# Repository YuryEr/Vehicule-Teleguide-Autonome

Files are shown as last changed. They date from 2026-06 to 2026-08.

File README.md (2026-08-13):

# Vehicule teleguide autonome (VTA)

PFE ELE795, Ecole de technologie superieure, ete 2026.  
Par : Yury Ereshchenko, Yoan Sapet, Vlad Alexandru Ilie, Ryan Leung et Serby Brian Barthelemy

Le sigle **VTA** sert partout ou la place manque : nom du point d'acces WiFi,
titre a l'ecran embarque, en-tetes des modules.

## Architecture materielle

- **Arduino UNO Q** : double processeur (Qualcomm QRB2210 MPU + STM32U585 MCU)
- **Hiwonder Tank** : chassis chenille, carte moteur I2C (0x34)
- **MPU-6050** : IMU gyroscope/accelerometre I2C (0x68)
- **Webcam USB** : detection routiere (YOLO, OpenCV). Cable modifie, alimentee
  par le convertisseur et non par le port USB-C
- **Bandeaux LED WS2812B** : 7 LEDs par bandeau : barre haute (gyrophare, feux de
  position), feux avant/arriere et clignotants de virage
- **Ecran TFT ILI9341** : 320x240, SPI materiel
- **HC-SR04** : capteur ultrason, detection de presence frontale (cone large)
- **TF-Luna** : LiDAR I2C (0x10), telemetre frontal (FOV 2 deg)
- **Servo SG90** : support orientable du LiDAR, sondage par secteurs
- **Convertisseur abaisseur (buck)** : rail 5V du montage, alimente depuis la
  batterie du chassis et non depuis l'UNO Q

## Architecture logicielle

    sketch/              MCU (STM32) : temps reel, capteurs, actionneurs
      sketch.ino           setup/loop, enregistrement des RPC Bridge
      config.h             Constantes materielles centralisees (broches, adresses, seuils)
      bus_i2c.h/cpp        Scan I2C unique au demarrage + cache de presence
      comm_bridge.h/cpp    Bridge RPC, reception des donnees de vision
      moteurs.h/cpp        Carte Hiwonder, encodeurs, I2C bas niveau
      imu.h/cpp            MPU-6050, calibration gyroscope
      deplacement.h/cpp    Machine a etats, joystick, asservissement encodeurs + gyro
      leds.h/cpp           Bandeaux WS2812B : barre, feux, clignotants
      ecran.h/cpp          Ecran ILI9341 : codes QR de connexion, infos reseau
      ultrason.h/cpp       HC-SR04, mesure d'echo bornee sur micros()
      lidar.h/cpp          TF-Luna, distance par I2C
      servo_lidar.h/cpp    SG90, PWM logiciel (support du LiDAR)
      obstacle.h/cpp       Fusion ultrason + LiDAR, sondage par secteurs
      securite.h/cpp       Veto sur les commandes moteur (mode autonome)
      evitement.h/cpp      Contournement lateral : sondage, rotation, longement
      test_capteurs.h/cpp  Releve serie periodique (bascule TEST_CAPTEURS_ACTIF)
      sketch.yaml          Profil de compilation, versions de librairies imposees

    python/              MPU (Qualcomm Linux) : serveur web, vision, Bridge
      main.py              Point d'entree, installation pip puis demarrage
      serveur_web.py       Flask + SocketIO, flux video, sequenceur de blocs
      comm_bridge.py       Communication Bridge RPC (MPU <-> MCU)
      vision.py            Feux (YOLO sur deux fenetres) et lignes
                           (seuillage adaptatif + centroide)
      boucle_vision.py     Anti-rebond des feux, cadences des deux boucles
      navigation.py        Suivi de ligne, correcteur proportionnel-derive
      requirements.txt     Dependances Python
      yolov8n.onnx         Modele de detection, entree figee a 256x256

    assets/              Interface web
      index.html           Page principale
      style.css            Styles
      app.js               Logique JS (joystick, Blockly, SocketIO)
      libs/blockly/        Editeur de blocs, embarque (pas de CDN)
      libs/socket.io.min.js  Client temps reel, embarque

Les deux librairies de `libs/` sont **embarquees volontairement** : en mode point
d'acces la carte n'a pas d'acces Internet, et un chargement par CDN laisserait
l'interface vide.

## Brochage

Toutes les broches numeriques sont declarees dans `sketch/config.h` : c'est la
seule source de verite du code. Les tableaux ci-dessous doivent lui correspondre.

### Alimentation

Le montage compte **trois sources distinctes**, et aucune ne provient du rail 5V
de l'UNO Q.

    Batterie du chassis
      |
      +---> Carte moteur Hiwonder (alimentation directe)
      |
      +---> Convertisseur abaisseur (buck) ---> Rail 5V du montage
      |                                           |
      |                                           +--> LiDAR TF-Luna
      |                                           +--> Ultrason HC-SR04
      |                                           +--> Servo SG90
      |                                           +--> Bandeaux LED WS2812B
      |                                           +--> Ecran ILI9341 (VCC et LED)
      |                                           +--> Webcam USB (VBUS seul)
      |
      +---> Masse commune <---------------------> GND de l'UNO Q

    L'UNO Q ne fournit que le 3.3V du connecteur Qwiic (IMU MPU-6050).
    Le port USB-C ne porte que les donnees de la camera, pas son alimentation.

| Composant | Tension | Source | Remarque |
|---|---|---|---|
| Carte moteur Hiwonder | Batterie | Batterie du chassis, directement | Jamais depuis l'UNO Q |
| IMU MPU-6050 | 3.3V | Connecteur Qwiic de l'UNO Q | Seul peripherique alimente par la carte |
| LiDAR TF-Luna | **5V** | Convertisseur abaisseur | **Pas** le 3.3V du Qwiic, voir plus bas |
| Ultrason HC-SR04 | 5V | Convertisseur abaisseur | Logique TRIG pilotee en 3.3V par l'UNO Q |
| Servo SG90 | 5V | Convertisseur abaisseur | Appels de courant au demarrage du mouvement |
| Bandeaux LED WS2812B | 5V | Convertisseur abaisseur | Voir le bilan de courant ci-dessous |
| Ecran ILI9341, `VCC` | **5V** | Convertisseur abaisseur | Le regulateur du module descend en 3.3V |
| Ecran ILI9341, `LED` | **5V** | Convertisseur abaisseur | Retroeclairage. Sous 3.3V l'ecran reste noir alors que le SPI repond |
| Webcam USB | 5V | Convertisseur abaisseur | **Cable modifie**, alimentation separee des donnees, voir plus bas |

**Le 5V vient d'un convertisseur abaisseur, pas de l'UNO Q.** Un module buck
descend la tension de la batterie du chassis a 5V et alimente tous les
peripheriques de puissance. Deux raisons : le rail 5V de la carte n'a pas la
reserve de courant necessaire aux bandeaux et au servo, et faire transiter ces
appels de courant par la carte de commande y ferait chuter la tension au moment
precis ou elle pilote.

**La masse doit rester commune, sinon rien ne fonctionne.** C'est la contrepartie
obligatoire d'une alimentation separee : le GND du convertisseur, celui de la
batterie et celui de l'UNO Q doivent etre relies. Les signaux de commande sortent
de l'UNO Q et sont lus par des composants alimentes ailleurs ; sans reference de
tension partagee, un niveau haut n'a plus de sens pour eux et rien ne repond,
alors que chaque bloc pris isolement semble correctement alimente.

**L'ecran a besoin de 5V sur ses deux entrees d'alimentation.** `VCC` traverse le
regulateur du module de decouplage, et `LED` alimente le retroeclairage. Une erreur
classique consiste a n'alimenter que `VCC` : le controleur repond correctement sur
le SPI, le code s'execute sans erreur, mais la dalle reste noire faute de
retroeclairage.

**Bilan de courant des bandeaux.** Un WS2812B consomme environ 60 mA au blanc
plein (20 mA par canal). Le montage porte 14 LEDs, soit **environ 840 mA** dans le
pire cas, `LUMINOSITE_BANDEAU` etant a 255. Le cas ne se presente pas en usage
normal, les feux etant blancs ou rouges et la barre rarement toute allumee, mais
c'est ce chiffre qui dimensionne le convertisseur : il doit tenir cette pointe en
plus du servo et des deux capteurs. Si les LEDs scintillent, verifier le calibre du
convertisseur avant de soupconner le code, et au besoin baisser
`LUMINOSITE_BANDEAU`.

### Webcam USB, cable modifie

Le cable de la camera est **ouvert et rebranche sur deux sources** : les quatre
conducteurs ne vont plus tous au meme endroit.

| Conducteur | Destination | Role |
|---|---|---|
| VBUS (rouge, 5V) | Convertisseur abaisseur | Alimentation de la camera |
| D+ (vert) | Port USB-C de l'UNO Q | Donnee |
| D- (blanc) | Port USB-C de l'UNO Q | Donnee |
| GND (noir) | Masse commune | Reference, partagee avec le convertisseur et l'UNO Q |

Deux raisons imposent ce montage, constatees sur cette carte :

1. **L'UNO Q n'alimente pas la camera par son port USB-C.** Le courant disponible
   sur ce port ne suffit pas a la faire demarrer.
2. **Brancher quoi que ce soit sur l'USB-C fait perdre le 5V de la carte.** Le
   rail 5V de l'UNO Q s'effondre des qu'un peripherique occupe ce port, ce qui
   priverait au passage tout ce qui en dependrait encore.

Prendre le VBUS sur le convertisseur resout les deux d'un coup : la camera a le
courant qu'il lui faut, et le port USB-C ne sert plus qu'a transporter les
donnees. **La masse doit rester commune** entre le convertisseur et l'UNO Q, sinon
la paire differentielle D+/D- n'a plus de reference et l'hote ne voit aucun
peripherique.

C'est aussi la raison pour laquelle l'ensemble du montage est alimente par le
convertisseur : le 5V de la carte n'est pas disponible de facon fiable des que la
camera est branchee.

### Vue d'ensemble des broches occupees

| Broche UNO Q | Utilisation |
|---|---|
| Qwiic (Wire1) | Carte moteur 0x34, IMU 0x68, LiDAR 0x10 |
| D2 | Ultrason : TRIG |
| D3 | Ultrason : ECHO |
| D5 | Servo SG90 : signal |
| D6 | Bandeau LED avant : data |
| D7 | Bandeau LED arriere : data |
| D8 | Ecran : RESET |
| D9 | Ecran : DC |
| D10 | Ecran : CS |
| D11 | Ecran : MOSI (SPI materiel) |
| D12 | Ecran : MISO (SPI materiel, non utilise en ecriture) |
| D13 | Ecran : SCK (SPI materiel) |

### Peripheriques I2C sur le bus Qwiic (`Wire1`)

Les trois peripheriques partagent le meme bus. Aucune adresse n'entre en conflit.

| Peripherique | Adresse | Alimentation | Particularite |
|---|---|---|---|
| Carte moteur Hiwonder | 0x34 | Alimentation propre du chassis | Aucune |
| IMU MPU-6050 | 0x68 | 3.3V du Qwiic | Aucune |
| LiDAR TF-Luna | 0x10 | **5V** du convertisseur | Broche **CFG a la masse** + power cycle |

**TF-Luna, alimenter en 5V.** Le capteur demande 3.7-5.2V ; le 3.3V du Qwiic est
sous son minimum. On utilise le Qwiic pour SDA/SCL/GND, mais VCC vient du rail
5V du convertisseur abaisseur.

**TF-Luna, CFG a la masse, puis power cycle.** CFG (broche 5) reliee a GND
selectionne le mode I2C. Le mode est **lu au demarrage du capteur** : apres avoir
branche CFG, il faut **couper et remettre l'alimentation**, sinon le capteur reste
en UART et n'apparait jamais sur le bus.

**Sans aucun peripherique sur le Qwiic**, les lignes flottent faute de resistances
de tirage et toutes les transactions I2C partent en timeout.

### Ultrason HC-SR04

| Broche du capteur | Broche UNO Q | Role |
|---|---|---|
| VCC | 5V du convertisseur | Alimentation |
| TRIG | D2 | Declenchement de la salve (impulsion 10 us) |
| ECHO | D3 | Duree de l'echo, en direct (sans pont diviseur) |
| GND | GND | Masse |

**ECHO se branche en direct.** Le montage a d'abord utilise un pont diviseur
22k/47k pour ramener la sortie 5V du capteur a ~3.4V. Il s'est avere inutile : la
liaison directe fonctionne correctement sur notre carte. A noter pour la
reproductibilite : la tolerance 5V des broches D de l'UNO Q n'est **pas garantie**
par Arduino (seuls certains pads STM32U585 sont 5V-tolerants, et jamais en mode
analogique). Le montage fonctionne, mais il sort de la plage documentee.

**TRIG est pilote en 3.3V** alors que le seuil du HC-SR04 se situe vers 3.5V.
Cela fonctionne sur nos exemplaires ; un capteur qui ne declencherait jamais est
la premiere piste a examiner.

### Servo de balayage SG90

| Fil du servo | Broche UNO Q | Role |
|---|---|---|
| Orange / jaune | D5 | Signal PWM (genere en logiciel) |
| Rouge | 5V du convertisseur | Alimentation |
| Brun / noir | GND | Masse, commune avec la carte et le convertisseur |

La librairie `Servo` est inutilisable sur ce core (voir plus bas) : l'impulsion est
generee par `servo_lidar.cpp`.

### Bandeaux LED WS2812B

| Broche du bandeau | Broche UNO Q | Role |
|---|---|---|
| DI (bandeau avant) | D6 | Donnees. Sur WS2813, relier BI a la meme broche |
| DI (bandeau arriere) | D7 | Donnees |
| VCC | 5V du convertisseur | Alimentation, voir le bilan de courant |
| GND | GND | Masse, commune avec la carte |

Chaque bandeau porte **7 LEDs en serie sur une seule ligne de donnees**, decoupees
en deux zones par le logiciel :

| Pixels | Zone | Role |
|---|---|---|
| 0 a 4 | Barre haute | Feux de position ou gyrophare |
| 5 | Feu droit | Blanc a l'avant, rouge a l'arriere, orange en clignotant |
| 6 | Feu gauche | Idem |

La logique de l'UNO Q est en 3.3V : le seuil des WS2812B est limite mais fonctionne
en pratique, aucun level-shifter n'a ete necessaire.

### Ecran TFT ILI9341 sur SPI materiel

| Broche de l'ecran | Broche UNO Q | Role |
|---|---|---|
| CS | D10 | Selection du peripherique |
| RESET | D8 | Reinitialisation |
| DC (ou RS) | D9 | Choix donnee / commande |
| SDI (MOSI) | D11 | Donnees vers l'ecran |
| SCK | D13 | Horloge SPI |
| SDO (MISO) | D12 | Donnees depuis l'ecran, non utilise en ecriture |
| VCC | **5V** du convertisseur | Alimentation du module |
| LED | **5V** du convertisseur | Retroeclairage, indispensable pour voir quoi que ce soit |
| GND | GND | Masse |

Les six lignes de signal sont celles declarees dans `config.h` et le materiel SPI de
la carte. Aucun level-shifter n'est necessaire : l'ILI9341 accepte la logique 3.3V
de l'UNO Q sur ses entrees de signal, mais son alimentation et son retroeclairage
demandent tous deux **5V**. Un ecran noir avec un SPI qui repond signale presque
toujours un `LED` non alimente.

## Librairies Arduino : versions critiques

Le core Zephyr de l'UNO Q ne supporte pas les librairies qui accedent directement
aux registres (style AVR). **Les versions ci-dessous sont obligatoires** : des versions
plus anciennes compilent parfois sans erreur mais ne fonctionnent pas au runtime.

```yaml
# sketch/sketch.yaml
profiles:
  default:
    fqbn: arduino:zephyr:unoq
    platforms:
      - platform: arduino:zephyr
    libraries:
      - Adafruit NeoPixel (1.15.5)
      - Adafruit GFX Library (1.12.6)
      - Adafruit ILI9341 (1.6.3)
      - Adafruit BusIO (1.17.4)
      - QRCode (0.0.1)
default_profile: default
```

| Librairie | Version | Pourquoi cette version |
|---|---|---|
| Adafruit NeoPixel | **1.15.5** | Les versions anterieures (ex. 1.12.0) **compilent** mais leur timing bit-bang 800 kHz ne produit **aucun signal** sur STM32U585/Zephyr. Symptome : LEDs completement eteintes. |
| Adafruit BusIO | **1.17.4** | Contient le guard `#elif defined(__MBED__) \|\| defined(__ZEPHYR__)` qui desactive `BUSIO_USE_FAST_PINIO`. Les versions < 1.15 **ne compilent pas** (erreur `portOutputRegister` / `digitalPinToPort`). |
| Adafruit GFX / ILI9341 | 1.12.6 / 1.6.3 | Dependances de l'ecran, dernieres versions stables. |
| QRCode | 0.0.1 | Generation des codes QR de connexion. C pur, sans acces registre ni allocation dynamique, le tampon est fourni par l'appelant, ce qui la rend compatible avec le core Zephyr. |

Les autres librairies visibles a la compilation (`Arduino_RouterBridge`, `Arduino_RPClite`,
`MsgPack`, `DebugLog`, `ArxTypeTraits`, `ArxContainer`, `Wire`) sont des dependances
**automatiques** du systeme Bridge et du core. Ne pas les epingler dans `sketch.yaml` :
elles forment un ensemble coherent livre avec le Bridge.

### Librairie a ne pas utiliser

**`Servo` est inutilisable sur ce core.** Des qu'elle coexiste avec NeoPixel, l'edition
de liens echoue sur `undefined reference to noInterrupts()/interrupts()`. Le servo de
balayage est donc pilote par un PWM logiciel dans `sketch/servo_lidar.cpp` : l'impulsion
est mesuree par attente active sur `micros()`, `delayMicroseconds()` etant imprecis sous
le scheduler Zephyr.

## Guide de deploiement sur Arduino UNO Q

### Prerequis

- Arduino App Lab installe (v0.8+)
- Arduino UNO Q connecte par USB au PC
- Webcam USB branchee

### Etape 1 : Configuration de l'Arduino UNO Q en mode point d'acces

Creer un point d'acces (AP), remplacer le SSID et le mot de passe :

```bash
nmcli device wifi hotspot ssid VTA password admin123 ifname wlan0
```

Appliquer automatiquement a chaque demarrage :

```bash
nmcli connection modify Hotspot connection.autoconnect yes
```

En mode point d'acces la carte n'a **pas d'acces Internet** : `main.py` ignore alors
l'installation pip (enveloppee dans un `try/except`) et demarre le serveur avec les
dependances deja presentes. Faire au moins un premier demarrage **connecte a Internet**
pour que les dependances Python s'installent.

### Etape 2 : Configuration des ports

Dans `app.yaml` a la racine du projet, s'assurer que le port du serveur web est expose :

```yaml
ports: [7000]
```

Sans cette ligne, le conteneur Docker tourne mais le port n'est pas accessible de l'exterieur.

### Etape 3 : Deployer le code

1. Ouvrir le projet dans Arduino App Lab
2. Cliquer **Run** (bouton vert)
3. App Lab va :
   - Compiler et flasher le sketch sur le MCU (STM32)
   - Creer un conteneur Docker sur le MPU (Qualcomm)
   - Installer automatiquement les dependances Python (premiere fois ~30s)
   - Demarrer le serveur web

### Etape 4 : Acceder a l'interface

1. Trouver l'IP de la carte (affichee en bas d'App Lab, ex: `192.168.137.52`)
2. Ouvrir dans un navigateur : `http://<IP>:7000`

### Depannage

| Probleme | Solution |
|---|---|
| Page web ne charge pas | Verifier `ports: [7000]` dans `app.yaml` |
| Camera non disponible | La camera USB n'est pas sur l'index attendu, le code scanne automatiquement `/dev/video0` a `/dev/video9`. Si aucun index ne repond, verifier le cable modifie : VBUS sur le convertisseur, D+ et D- sur l'USB-C, **masse commune**. Sans masse partagee la paire differentielle n'a pas de reference et l'hote ne detecte aucun peripherique |
| Terminal Python vide | Les dependances pip s'installent au premier demarrage, patienter ~30s |
| Erreur `ModuleNotFoundError` | Verifier que `requirements.txt` est a jour et relancer Run |
| Le serveur ne demarre pas hors ligne | `main.py` enveloppe l'install pip dans un `try/except` : en mode point d'acces (sans Internet) l'install est ignoree et le serveur demarre quand meme |
| `Error: verify failed in bank at 0x08000000` | Le flash a echoue : le MCU tourne **l'ancien code**. Relancer Run (parfois 2-3 fois) jusqu'a un flash propre. Si une modification semble sans effet, c'est souvent ca. |
| `ld: file truncated` / `invalid string offset` / segfault du linker | Cache de compilation corrompu. Supprimer `.cache/sketch` sur la carte (garder `.cache/.venv` qui contient l'environnement Python) : `rm -rf ~/ArduinoApps/tankets_ele795/.cache/sketch` |
| LEDs completement eteintes | Verifier `Adafruit NeoPixel (1.15.5)` dans `sketch.yaml`, les versions anterieures compilent mais ne pilotent rien |
| Ecran : erreur `portOutputRegister` a la compilation | Verifier `Adafruit BusIO (1.17.4)`, les versions < 1.15 ne compilent pas sur Zephyr |
| Ecran noir alors que le code s'execute | La broche `LED` du module n'est pas alimentee. Le controleur repond sur le SPI et le programme se deroule normalement, mais sans retroeclairage la dalle reste noire. `VCC` **et** `LED` demandent 5V |
| LEDs qui scintillent | Calibre du convertisseur abaisseur. 14 WS2812B au blanc plein demandent environ 840 mA, en plus du servo et des capteurs. Verifier le convertisseur avant le code, au besoin baisser `LUMINOSITE_BANDEAU` |
| Un peripherique alimente ne repond a rien | Masse commune. Le convertisseur, la batterie et l'UNO Q doivent partager leur GND, sans quoi les signaux de commande n'ont plus de reference et chaque bloc semble pourtant correctement alimente |
| Servo qui tremble sur place sans se deplacer | Comportement attendu si `SERVO_MAINTIEN_MS` est augmente : chaque impulsion regeneree porte le jitter de l'attente active. Le train d'impulsions doit s'arreter une fois la cible atteinte |
| LiDAR `capteur present : NON` | CFG (broche 5) a la masse ? Alimentation >= 3.7V ? **Power cycle apres avoir branche CFG** ? SDA/SCL non inverses ? |
| Un capteur absent rend la carte muette | Le Bridge est enregistre **avant** les inits materielles dans `setup()`, donc le controle survit a un capteur defaillant. Si le probleme persiste, verifier qu'aucune init bloquante n'a ete deplacee avant les `provide_safe`. |
| `[Bridge.read_loop] 'utf-8' codec can't decode byte ...` puis tous les RPC qui expirent apres 10 s | La sortie serie du MCU partage son lien avec les RPC du Bridge. Sous une ecriture serie soutenue, le multiplexage perd une frontiere de trame et la boucle de lecture du Bridge meurt : plus aucun appel n'aboutit jusqu'au redemarrage. **Commenter `TEST_CAPTEURS_ACTIF` dans `test_capteurs.h`**, et n'ecrire sur le port serie que ponctuellement. Symptome typique : une sequence de blocs qui casse apres une dizaine de commandes. |

### Diagnostic I2C

Pour verifier ce qui repond sur le bus Qwiic, ajouter temporairement dans `setup()`
apres `Wire1.begin()` :

```cpp
for (uint8_t addr = 1; addr < 127; addr++) {
    Wire1.beginTransmission(addr);
    if (Wire1.endTransmission() == 0) {
        Serial.print("[i2c] Trouve a 0x");
        Serial.println(addr, HEX);
    }
}
```

Attendu : `0x34` (moteurs), `0x68` (IMU), `0x10` (LiDAR).

## Conventions de code

- **Python** : snake_case (fonctions, variables, fichiers)
- **JavaScript** : camelCase (fonctions, variables), UPPER_CASE (constantes)
- **HTML** : kebab-case (IDs, classes)
- **C/Arduino** : PascalCase + prefixe module (ex: `CommBridge_Initialiser`)
- **Fichiers .h** : documentation en francais, format bloc majuscule
- **Constantes materielles** : centralisees dans `sketch/config.h`, jamais dans les modules
- **Modules capteurs** : pattern `X_Initialiser()` / `X_MettreAJour()` / `X_Valeur()`,
  avec mise en cache non bloquante rafraichie dans `loop()`

## Modes de conduite

Le MCU connait deux regimes, fixes par la RPC `definir_mode`. L'interface web
ajoute un troisieme usage, le mode blocs, qui n'est pas un mode du MCU mais une
sequence de commandes envoyees depuis le MPU.

| Mode | Veto de securite | Origine des commandes |
|---|---|---|
| Manuel | Aucun | Joystick de l'interface web |
| Autonome | Actif | Suivi de ligne calcule sur le MPU |
| Blocs | Aucun | Sequenceur de `serveur_web.py`, un bloc a la fois |

**Le veto ne s'applique qu'en mode autonome.** En manuel le pilote voit le
vehicule et garde le controle complet, y compris pour l'approcher volontairement
d'un obstacle. Le laisser actif rendrait le pilotage incomprehensible, la carte
refusant des commandes sans que rien ne l'explique a l'ecran.

Le veto ne bloque que les **avances**, c'est-a-dire les commandes ou les deux
chenilles poussent vers l'avant. Les rotations et la marche arriere restent
autorisees : ce sont precisement les manoeuvres qui degagent le vehicule.

Deux causes distinctes le declenchent, et elles n'ont pas la meme suite :

| Cause | Consequence |
|---|---|
| Obstacle sous `OBSTACLE_SEUIL_CM` | Arret, puis lancement du contournement |
| Feu rouge ou jaune detecte | Arret seul, reprise des que le feu passe au vert |

Le jaune est traite comme le rouge : devant un feu sur le point de changer,
s'arreter est le comportement attendu. Une detection de feu expire au bout de
`FEU_AGE_MAX_MS`, faute de quoi une perte de la liaison de vision immobiliserait
le vehicule indefiniment.

## Detection d'obstacles et contournement

### Fusion des deux capteurs

La distance frontale retenue est la **plus petite des mesures valides** entre
l'ultrason et le LiDAR. Les deux capteurs ne mesurent pas la meme chose et c'est
la raison de les garder tous les deux :

| Capteur | Champ | Role |
|---|---|---|
| HC-SR04 | Cone large | Presence d'un obstacle quelque part devant |
| TF-Luna | 2 degres | Telemetre precis, mais aveugle a ce qui n'est pas dans l'axe |

Un LiDAR seul manque un obstacle decale de quelques degres ; un ultrason seul
donne une distance grossiere. Chaque mesure est ramenee au pare-choc avant par
`ULTRASON_RECUL_CM` et `LIDAR_RECUL_CM`, sans quoi la fusion comparerait deux
distances prises depuis deux origines differentes.

### Machine a etats du contournement

Le servo n'existe que pour le sondage : il n'y a pas de balayage permanent, le
champ du LiDAR etant trop etroit pour cartographier quoi que ce soit en un temps
raisonnable.

Le trajet forme un **trapeze** : une diagonale qui ecarte le vehicule de la
ligne, un segment parallele qui depasse l'obstacle, puis une diagonale de retour
vers la ligne.

                       EVITEMENT_LONGEMENT_M
                      +---------------+           segment parallele a la ligne
                     /                 \      angles 1 et 2 : ANGLE_DEG
        ____________/    [obstacle]     \___  angle 3 : ANGLE_RETOUR_DEG
             ligne suivie

    REPOS
      | obstacle detecte en mode autonome
      v
    PAUSE --> SONDAGE             trois secteurs, +/- OBSTACLE_ECART_SONDAGE_DEG
      |                           retient le cote le plus degage
      v
    PAUSE --> ROTATION_ALLER      pivote de EVITEMENT_ANGLE_DEG vers ce cote
      |
      v
    PAUSE --> AVANCE_DIAGONALE    avance de EVITEMENT_DISTANCE_M
      |
      v
    PAUSE --> ROTATION_PARALLELE  rend l'angle d'ecartement, cap parallele
      |                           a la ligne
      v
    PAUSE --> AVANCE_PARALLELE    avance de EVITEMENT_LONGEMENT_M
      |
      v
    PAUSE --> ROTATION_RETOUR     EVITEMENT_ANGLE_RETOUR_DEG vers la ligne
      |
      v
    REPOS                         le suivi de ligne reprend la main

**Chaque etape est precedee d'une immobilisation de `EVITEMENT_PAUSE_MS`.** La
carte moteur maintient sa derniere consigne tant qu'on ne lui en donne pas
d'autre : sans arret explicite, les etapes s'enchainent en roulant et se
superposent.

**Les trois rotations ne sont pas dans le meme sens.** La premiere ecarte de la
ligne, du cote retenu par le sondage. Les deux suivantes vont a l'oppose : la
deuxieme rend exactement l'angle d'ecartement et remet le cap d'origine, la
troisieme dirige le vehicule vers la ligne, qu'il recroise. Sans cette troisieme
rotation, il roulerait parallelement a la ligne sans jamais la revoir et le
suivi s'arreterait apres `MISS_MAX` cycles.

**La rotation de retour est plus faible que celle d'ecartement**, et pour une
raison qui n'a rien de geometrique : a 45 degres la ligne sort du champ de la
camera avant d'etre recroisee, et le suivi s'arrete sans jamais la retrouver.
A 20 degres elle reste en vue, au prix d'une approche plus longue.

| Angle de retour | Distance parcourue avant de recroiser la ligne |
|---|---|
| 45 degres | 45 cm, mais ligne hors du champ |
| 30 degres | 64 cm |
| **20 degres** | **93 cm, valeur retenue** |
| 15 degres | 123 cm |

**La deuxieme rotation rend l'angle cumule, pas une valeur fixe.** Si la voie
reste bloquee apres la premiere rotation, un cran supplementaire est ajoute,
jusqu'a `EVITEMENT_ESSAIS_MAX` fois. La remise parallele doit alors annuler le
total, sans quoi le segment cense etre parallele partirait de travers.

**Dimensionnement.** L'ecart lateral obtenu vaut `EVITEMENT_DISTANCE_M` multiplie
par le sinus de l'angle d'ecartement, soit 32 cm pour 45 cm a 45 degres. Noter
que la constante decrit la distance **parcourue** sur la diagonale, pas l'ecart
obtenu. Il doit depasser le
demi-encombrement de l'obstacle, sans quoi le segment parallele le percute. Le
segment parallele doit lui-meme depasser la profondeur de l'obstacle avant que le
vehicule ne se reoriente vers la ligne.

## Ecran de connexion

L'ecran affiche une page unique portant **deux codes QR cote a cote**, de facon
qu'un visiteur puisse rejoindre le vehicule sans que personne ne lui dicte un mot
de passe.

| Code QR | Contenu | Effet au scan |
|---|---|---|
| Gauche | `WIFI:T:WPA;S:<ssid>;P:<mdp>;;` | Propose de rejoindre le point d'acces |
| Droite | `http://<ip>:7000` | Ouvre l'interface dans le navigateur |

Le format d'adhesion WiFi `WIFI:` est un schema de fait defini par le projet
ZXing, reconnu nativement par iOS 11 et par Android 10 et versions ulterieures.

| Constante | Valeur | Role |
|---|---|---|
| `QR_VERSION` | 3 | 29x29 modules, 53 octets en correction basse |
| `QR_TAILLE_MODULE` | 4 | Cote d'un module, en pixels |
| `QR_ZONE_SILENCE` | 4 | Marge blanche en modules, exigee par la norme |

La zone de silence n'est pas decorative : sans elle, un lecteur ne delimite pas
le symbole et le scan echoue sur la plupart des telephones.

### Origine des trois informations

Les trois valeurs sont des constantes de `sketch/config.h`, et **doivent
correspondre a la commande `nmcli` du guide de deploiement** :

| Constante | Valeur | Origine |
|---|---|---|
| `RESEAU_SSID` | `VTA` | Choisi dans la commande `nmcli` |
| `RESEAU_MOT_DE_PASSE` | `admin123` | Idem |
| `RESEAU_IP` | `10.42.0.1` | Consequence de la commande, voir ci-dessous |

L'adresse n'est pas arbitraire : en mode partage, NetworkManager attribue
**10.42.0.1** a l'interface et distribue le reste du sous-reseau 10.42.0.0/24
aux clients. Creer le point d'acces fixe donc l'adresse au meme titre que le
SSID, et rien n'a besoin de la decouvrir a l'execution.

**Cela ne tient que si la carte cree son reseau.** Si elle en rejoint un, son
adresse vient d'un DHCP : il faut alors la relever avec `ip addr show wlan0` et
la reporter dans `config.h`. C'est la contrepartie assumee de la simplicite,
acceptable parce que le mode point d'acces est celui du deploiement.

## Signalisation lumineuse

Chaque bandeau porte 7 LEDs sur une seule ligne de donnees, decoupees en deux
zones par le logiciel. Les deux zones partagent la meme luminosite materielle :
le contraste entre la barre et les feux se fait par les valeurs RVB.

| Zone | Pixels | Comportement |
|---|---|---|
| Barre haute | 0 a 4 | Eteinte, feux de position, ou gyrophare (`PERIODE_GYROPHARE_MS`) |
| Feux | 5 et 6 | Blancs a l'avant, rouges a l'arriere |
| Clignotants | 5 ou 6 | Orange sur le cote du virage (`PERIODE_CLIGNOTANT_MS`) |

Le cote de chaque pixel est fixe par `PIXEL_COTE_DROIT` et `PIXEL_COTE_GAUCHE` :
les bandeaux avant et arriere se faisant face, l'ordre physique des pixels
s'inverse de l'un a l'autre.

## Contrat RPC Bridge (Python vers MCU)

| Fonction | Parametres | Description |
|---|---|---|
| `joy_x`, `joy_y` | float | Pilotage manuel joystick |
| `roues` | int, int (0-100, positifs) | Vitesse par cote, suivi de ligne |
| `avancer_metres` | float (positif) | Deplacement avant asservi |
| `reculer_metres` | float (positif) | Deplacement arriere asservi |
| `tourner_gauche_deg` | float (positif) | Rotation gauche asservie |
| `tourner_droite_deg` | float (positif) | Rotation droite asservie |
| `arreter_mouvement` | aucun | Arret d'urgence |
| `mouvement_actif` | aucun, retourne int (0/1) | Polling fin de mouvement |
| `definir_mode` | int | 0=manuel (aucun veto), 1=autonome (veto sur obstacle) |
| `veto_actif` | aucun, retourne int (0/1) | Le MCU refuse-t-il d'avancer ? |
| `cause_arret` | aucun, retourne int | 0=voie libre, 1=obstacle, 2=feu rouge ou jaune |
| `mode_bandeaux` | int | Barre haute : 0=eteint, 1=position, 2=gyrophare |
| `mode_phares` | int (0/1) | Feux : blanc a l'avant, rouge a l'arriere |
| `lire_ultrason_cm` | aucun, retourne int | Distance frontale HC-SR04 (cm), plafond `ULTRASON_DISTANCE_MAX` = voie degagee |
| `lire_lidar_cm` | aucun, retourne int | Distance frontale TF-Luna (cm), -1 si invalide |
| `servo_angle` | int (0-180) | Oriente le servo de balayage, 90 = droit devant |
| `obstacle_frontal_cm` | aucun, retourne int | Distance fusionnee ultrason + LiDAR (cm) |
| `obstacle_detecte` | aucun, retourne int (0/1) | Obstacle sous `OBSTACLE_SEUIL_CM` |
| `lancer_sondage` | aucun | Sonde les trois secteurs (~1 s, vehicule a l'arret) |
| `cote_degage` | aucun, retourne int | 0 = sondage en cours, 1 = gauche, 2 = droite |

RPC dans l'autre sens (MCU recoit du MPU) : `on_feu(bool, int, int)`. L'ecart de
ligne n'est pas transmis au MCU : le suivi de ligne est calcule sur le MPU, qui
n'envoie que la consigne de vitesse par `roues`.

**Note** : le Bridge ne transmet pas correctement les nombres negatifs. Toujours envoyer
des valeurs positives, le sens est gere par des fonctions dediees cote MCU (c'est
pourquoi `roues` prend deux vitesses positives plutot qu'un differentiel signe).

## Detection des feux de signalisation

L'entree du modele YOLOv8n exporte en ONNX est **figee a 256 pixels de cote**.
Redimensionner l'image entiere pour l'y faire tenir divise la largeur apparente
des objets par plus de deux : un feu de 6 cm vu a 1 m passe d'environ 33 pixels
a 13, en dessous de ce que le modele detecte de facon fiable. C'est pourquoi le
feu n'etait vu qu'au dernier moment.

Le modele recoit donc des **fenetres prelevees a la resolution native** plutot
que l'image comprimee. Deux fenetres, aux bords gauche et droit : le feu borde
la chaussee et n'apparait jamais au centre du champ.

    Image capturee par la webcam : 640 x 360

    x=0          x=256   x=384        x=640
    +--------------+-------+--------------+   y=0
    |##############|       |##############|
    |## FENETRE  ##| bande |## FENETRE  ##|
    |##  GAUCHE  ##|  non  |##  DROITE  ##|
    |##256 x 256 ##|analyse|##256 x 256 ##|
    |##############| 128px |##############|
    |XXXXXXXXXXXXXX|=======|XXXXXXXXXXXXXX|   y=216
    +--------------+=======+--------------+   y=256
    |=====================================|
    |== ROI SUIVI DE LIGNE : 640 x 144 ===|
    +-------------------------------------+   y=360

    ###  fenetres soumises au modele, prelevees a la resolution native
    ===  region du seuillage adaptatif et du centroide de la ligne
    XXX  recouvrement des deux traitements, 40 pixels de haut

Les deux traitements lisent la meme image mais ne s'ignorent pas
geometriquement : les fenetres descendent jusqu'a `y = 256` et le ROI de ligne
commence a `y = 216`, soit 40 pixels communs. Sans consequence, les deux chaines
etant independantes, mais a savoir avant de deplacer l'une ou l'autre.

Une bande centrale de 128 pixels de large n'est jamais soumise au modele. C'est
sans consequence pour un feu de bord de voie, mais un feu place au centre du
champ ne serait pas detecte.

Le feu conserve ainsi sa taille reelle, ce qui **double environ la portee de
detection** sans avoir a reexporter le modele.

Les deux fenetres impliquent **deux inferences par cycle**. Si la charge du MPU
devient genante, augmenter `PERIODE_INFERENCE` dans `boucle_vision.py` : un feu
est immobile, sa detection ne demande pas une cadence elevee.

La couleur du feu n'est pas donnee par le modele, qui ne connait que la classe
`traffic light` de COCO. Elle est determinee ensuite, par comptage de pixels dans
trois plages HSV appliquees a la boite detectee. Le rouge occupe **deux** plages,
la teinte passant par zero en HSV.

Les constantes de reglage sont regroupees plus bas, dans **Constantes de reglage
du MPU**.

## Suivi de ligne autonome

Le module `python/navigation.py` implemente un correcteur **proportionnel-derive** :
la vision fournit l'ecart lateral (pixels) entre le centre de la ligne et le centre
de l'image, et on ralentit la roue du cote vers lequel tourner. Les deux roues avancent
toujours (valeurs positives, contrainte du Bridge).

Le terme derive est indispensable : la vision tourne a 10 Hz et le Bridge ajoute sa
latence. Avec un correcteur purement proportionnel, la correction arrive alors que
l'ecart a deja change de signe : le vehicule oscille d'un bord a l'autre et finit par
perdre la ligne.

| Constante | Valeur | Role |
|---|---|---|
| `VITESSE_BASE` | 15 | Vitesse des deux roues en ligne droite (0-100) |
| `KP_LATERAL` | 0.015 | Gain proportionnel : pixels d'ecart vers unites de vitesse |
| `KD_LATERAL` | 0.035 | Gain derive : s'oppose aux variations de l'ecart, amortit le depassement |
| `ZONE_MORTE_PX` | 35 | Ecart en deca duquel la ligne est jugee centree |
| `CORRECTION_MAX` | 8 | Correction maximale, garde les deux roues en avant |
| `SENS` | -1 | Oriente la correction. **-1** est la valeur validee sur le montage actuel, a reprendre si la camera est reorientee |
| `MISS_MAX` | 8 | Cycles sans ligne avant l'arret |

### Procedure de reglage

Un seul parametre a la fois, dans cet ordre, sinon il est impossible de savoir
lequel agit.

1. **`KD_LATERAL = 0`**, puis diviser `KP_LATERAL` par deux jusqu'a disparition de
   l'oscillation. Le vehicule sera mou en virage : c'est attendu. Noter la valeur.
2. **Remonter `KD_LATERAL`** par paliers jusqu'a retrouver du mordant en virage sans
   redepasser. Trop haut, il rend le vehicule nerveux sur le bruit du centroide.
3. **`ZONE_MORTE_PX`** : augmenter jusqu'a ce que le vehicule cesse de fretiller en
   ligne droite. Trop haute, il louvoie lentement autour de la ligne.
4. **`VITESSE_BASE`** en dernier. Toute augmentation de vitesse deteriore un reglage
   trouve plus lentement, et impose de reprendre a l'etape 1.

`KP_LATERAL` et `KD_LATERAL` dependent de la **resolution de la camera**, l'ecart etant
exprime en pixels bruts. Un changement de resolution invalide tout le reglage.

## Constantes de reglage du MCU

Toutes dans `sketch/config.h`. Les valeurs indiquees sont celles du montage
actuel ; celles marquees d'une etoile ont ete relevees par la mesure, les autres
sont des valeurs d'origine ou reprises d'une documentation.

### Calibration mecanique

| Constante | Valeur | Role |
|---|---|---|
| `DIAMETRE_ROUE_MM` | 65.0 | Diametre du barbotin |
| `RATIO_REDUCTEUR` | 50.0 | **Jamais mesure**, voir l'avertissement ci-dessous |
| `IMPULSIONS_PAR_TOUR` | 44.0 | Impulsions par tour d'aimant du JGB37-520 |
| `SENSIBILITE_GYRO` | 131.0 | LSB par deg/s a pleine echelle +/-250 |

`DIAMETRE_ROUE_MM` et `RATIO_REDUCTEUR` n'interviennent que par leur **produit**
dans `Moteurs_PulsesEnMetres`, et le glissement de la chenille s'y cache : ce sont
des constantes ajustees par la mesure, pas des grandeurs relevables sur une fiche
produit. Le fabricant annonce 90 pour le JGB37-520, valeur qui donne le double de
la distance reelle sur ce chassis. Reglage : commander 2 m, mesurer, puis
`RATIO_nouveau = RATIO_actuel * (commandee / mesuree)`.

### Deplacements asservis

| Constante | Valeur | Role |
|---|---|---|
| `VITESSE_DEPLACEMENT` | 12 | Translation, en impulsions par 10 ms |
| `VITESSE_ROTATION` | 11 | Rotation, volontairement lente pour la reproductibilite |
| `ROT_MARGE_ARRET_DEG` | 10.0 * | Compensation de l'inertie de fin de rotation |
| `ROT_MARGE_LENTE_DEG` | 20.0 | Debut de l'approche lente, a garder au-dessus de la marge d'arret |
| `AVANCE_TRIM_NUM` / `_DEN` | 5 / 16 * | Compensation de derive, fraction d'unite de consigne |
| `REEMISSION_MOTEUR_MS` | 100 | Repetition de la consigne pendant un mouvement asservi |
| `TIMEOUT_AVANCE_MS` | 12000 | Abandon d'une avance qui n'aboutit pas |
| `TIMEOUT_ROTATION_MS` | 8000 | Abandon d'une rotation qui n'aboutit pas |

En boucle fermee, l'unite de vitesse est le **nombre d'impulsions par 10 ms** et
la plage utile va jusqu'a environ 50 selon la charge et la tension.

Toute modification de `VITESSE_ROTATION` impose de reprendre les deux marges :
commander 90 puis 180 degres et mesurer. Un ecart **constant** designe l'inertie,
donc `ROT_MARGE_ARRET_DEG` ; un ecart **proportionnel** designe `SENSIBILITE_GYRO`.

Le trim de derive est regle **pour 1 m**. Sur 2 m le vehicule decrit une legere
courbe en S : un transitoire de demarrage s'ajoute a la derive etablie, et une
constante ne peut annuler leur somme qu'a une seule distance.

### Pilotage manuel

| Constante | Valeur | Role |
|---|---|---|
| `VITESSE_JOYSTICK` | 80 | Sensibilite unique, appliquee lineairement aux deux axes |

La consigne envoyee vaut `(y -/+ x) * VITESSE_JOYSTICK` par cote. L'interface
bornant la poignee a un cercle, la diagonale a 45 degres produit une consigne de
113 que `Moteurs_DefinirVitesse` ecrete a 100 : un seul cote etant tronque, le
rayon de virage se resserre legerement a pleins gaz.

### Detection d'obstacles et contournement

| Constante | Valeur | Role |
|---|---|---|
| `OBSTACLE_SEUIL_CM` | 25 * | En deca, obstacle signale. **A garder nettement au-dessus de `LIDAR_DISTANCE_MIN`** |
| `OBSTACLE_PERIODE_MS` | 50 | Reevaluation de la distance frontale |
| `OBSTACLE_ECART_SONDAGE_DEG` | 45 | Ecart des secteurs lateraux sondes |
| `OBSTACLE_SENS_SERVO` | -1 | -1 si gauche et droite sont inverses mecaniquement |
| `OBSTACLE_STABILISATION_MS` | 40 | Attente apres l'arrivee du servo, avant la mesure |
| `EVITEMENT_ANGLE_DEG` | 45 | Rotations d'ecartement et de remise parallele |
| `EVITEMENT_ANGLE_RETOUR_DEG` | 20 * | Rotation finale vers la ligne. Plus faible pour la garder dans le champ de la camera |
| `EVITEMENT_DISTANCE_M` | 0.45 | Diagonale d'ecartement, donne 32 cm d'ecart lateral |
| `EVITEMENT_LONGEMENT_M` | 0.20 | Segment parallele a la ligne, doit depasser l'obstacle |
| `EVITEMENT_PAUSE_MS` | 400 | Immobilisation entre deux etapes |
| `EVITEMENT_ESSAIS_MAX` | 3 | Rotations d'ecartement avant d'abandonner |
| `ULTRASON_RECUL_CM` | 0 | Recul du capteur par rapport au pare-choc, **a mesurer sur la coque finale** |
| `LIDAR_RECUL_CM` | 0 | Idem |

### Capteurs

| Constante | Valeur | Role |
|---|---|---|
| `ULTRASON_DISTANCE_MAX` | 100 | Portee utile (cm), valeur plafond = voie degagee |
| `ULTRASON_PERIODE_MS` | 100 | Rafraichissement, environ 10 Hz |
| `ULTRASON_TIMEOUT_US` | 6000 | 100 cm aller-retour font environ 5.8 ms |
| `ULTRASON_TIMEOUT_PRESENCE_US` | 60000 | Au-dela de 38 ms : echo emis sans obstacle |
| `LIDAR_FORCE_MIN` | 100 | En dessous, signal juge trop faible |
| `LIDAR_DISTANCE_MIN` | 20 | Zone morte declaree par la fiche technique |
| `LIDAR_DISTANCE_MAX` | 800 | Portee fiable (cm) |
| `LIDAR_PERIODE_MS` | 100 | Rafraichissement, environ 10 Hz |
| `SERVO_ANGLE_MIN` / `_MAX` / `_CENTRE` | 0 / 180 / 90 | 90 degres pointe droit devant |
| `SERVO_MS_PAR_DEGRE` | 5 | Environ 200 deg/s, le SG90 plafonnant vers 300 |
| `SERVO_PULSE_MIN_US` / `_MAX_US` | 600 / 2400 | Largeurs d'impulsion a 0 et 180 degres |
| `SERVO_MAINTIEN_MS` | 400 | Duree du train d'impulsions apres l'arrivee a la cible |
| `DLPF_20HZ` | 4 | Bande passante du gyroscope ramenee a 20 Hz |
| `IMU_CAL_ECHANTILLONS` | 200 | Calibration longue au demarrage |
| `IMU_CAL_ECHANTILLONS_RAPIDE` | 40 | Rezero avant chaque mouvement asservi |
| `IMU_CAL_DISPERSION_MAX` | 3.0 | Au-dela, en deg/s, le vehicule bougeait : calibration rejetee |
| `FEU_AGE_MAX_MS` | 3000 | Peremption d'une detection de feu |
| `LUMINOSITE_BANDEAU` | 255 | Gain global des bandeaux, voir le bilan de courant |
| `RESEAU_SSID` | `"VTA"` | Doit correspondre a la commande `nmcli` du deploiement |
| `RESEAU_MOT_DE_PASSE` | `"admin123"` | Idem |
| `RESEAU_IP` | `"10.42.0.1"` | Defaut de NetworkManager en mode partage |
| `NOM_COURT` | `"VTA"` | Titre affiche a l'ecran, le nom complet n'y tient pas |

Le train d'impulsions du servo **s'arrete** une fois la position tenue. A l'arret,
chaque impulsion regeneree porte le jitter de l'attente active et redemande donc
une position legerement differente : le servo vibrerait sur place sans se deplacer.
Sans signal, le reducteur maintient l'angle, la charge du support etant faible.

## Constantes de reglage du MPU

| Constante | Fichier | Valeur | Role |
|---|---|---|---|
| `LARGEUR_CAPTURE` x `HAUTEUR_CAPTURE` | `serveur_web.py` | 640 x 360 | Resolution de capture, 16/9 comme le capteur |
| `CADENCE_CAPTURE` | `serveur_web.py` | 30 | Images par seconde |
| `PERIODE_LIGNES` | `boucle_vision.py` | 0.10 | Cadence du suivi de ligne (10 Hz) |
| `PERIODE_INFERENCE` | `boucle_vision.py` | 0.30 | Cadence des inferences YOLO |
| `REBOND_ACTIVATION` | `boucle_vision.py` | 2 | Detections consecutives avant de signaler un feu |
| `REBOND_DESACTIVATION` | `boucle_vision.py` | 4 | Cycles sans feu avant de le declarer absent |
| `TAILLE_INFERENCE` | `vision.py` | 256 | Cote de la fenetre. **Doit correspondre a l'`imgsz` d'export du modele** |
| `SEUIL_CONFIANCE` | `vision.py` | 0.40 | Un feu lointain sort avec une confiance plus basse |
| `SEUIL_NMS` | `vision.py` | 0.45 | Recouvrement au-dela duquel deux boites fusionnent |
| `THREADS_ORT` | `vision.py` | 2 | Threads laisses a ONNX Runtime |
| `ROI_HAUT_LIGNES` | `vision.py` | 0.60 | Haut du ROI de ligne, donc les 40 % du bas |
| `PIXELS_MIN_LIGNE` | `vision.py` | 800 | En deca, aucune ligne n'est declaree |

`CHEMIN_MODELE`, `TAILLE_INFERENCE` et `THREADS_ORT` sont surchargeables par
variable d'environnement, ce qui permet d'essayer un autre export du modele sans
toucher au code.

## References

### Code adapte

- YOLO Live Object Detection, exemple Arduino App Lab (2025). Base du
  chargement du modele ONNX et du post-traitement des sorties dans
  `python/vision.py`.
- Exemple officiel Hiwonder pour carte moteur a encodeur. Origine des
  adresses de registres (0x14, 0x15, 0x33, 0x3C), de leurs unites et de la
  valeur de vitesse de translation, reprises dans `sketch/config.h` et
  `sketch/moteurs.cpp`.

### Algorithmes

- Seuillage adaptatif gaussien, extraction de la ligne
  OpenCV documentation, Image Thresholding
  https://docs.opencv.org/4.x/d7/d4d/tutorial_py_thresholding.html
- Moments d'image, calcul du centroide de la ligne
  Hu, M.-K. (1962). Visual Pattern Recognition by Moment Invariants.
  IRE Transactions on Information Theory, 8(2), 179-187.
- Ouverture morphologique, nettoyage du masque binaire
  Serra, J. (1982). Image Analysis and Mathematical Morphology.
  Academic Press.
- Non-Maximum Suppression, fusion des detections des deux fenetres
  Neubeck, A., & Van Gool, L. (2006). Efficient Non-Maximum Suppression.
  ICPR 2006.
- Espace colorimetrique HSV, classification de la couleur du feu
  Smith, A. R. (1978). Color Gamut Transform Pairs. SIGGRAPH '78.
- Correcteur proportionnel-derive, suivi de ligne
  Ogata, K. (2010). Modern Control Engineering, 5e edition. Prentice Hall.

### Bibliotheques

| Bibliotheque | Reference | Usage |
|---|---|---|
| YOLOv8n | Jocher et al. (2023), Ultralytics, https://github.com/ultralytics/ultralytics | Detection des feux |
| ONNX Runtime | Microsoft (2021), https://onnxruntime.ai/ | Inference du modele |
| OpenCV | Bradski, G. (2000). The OpenCV Library. Dr. Dobb's Journal, https://opencv.org/ | Capture et traitement d'image |
| NumPy | Harris et al. (2020). Array programming with NumPy. Nature, 585, 357-362 | Calcul sur les sorties du modele |
| Flask | https://flask.palletsprojects.com/ | Serveur web |
| Flask-SocketIO | https://flask-socketio.readthedocs.io/ | Evenements temps reel |
| Eventlet | https://eventlet.net/ | Boucle d'evenements du serveur |
| Socket.IO (v4) | https://socket.io/ | Client temps reel du navigateur |
| Blockly | Google, https://developers.google.com/blockly | Editeur de sequences par blocs |
| Adafruit NeoPixel | https://github.com/adafruit/Adafruit_NeoPixel | Pilotage des bandeaux WS2812B |
| Adafruit GFX, ILI9341, BusIO | https://github.com/adafruit | Affichage sur l'ecran TFT |
| QRCode (Arduino) | Richard Moore (ricmoo), licence MIT, https://github.com/ricmoo/QRCode | Codes QR de connexion |
| Arduino_RouterBridge | Fourni avec le core `arduino:zephyr` | RPC entre le MPU et le MCU |

### Donnees

- Classes COCO, identifiant 9 pour `traffic light`
  Lin, T.-Y. et al. (2014). Microsoft COCO: Common Objects in Context.
  ECCV 2014. https://cocodataset.org/

### Normes et specifications

- ISO/IEC 18004:2015, QR Code bar code symbology specification
- Format d'adhesion WiFi `WIFI:` : projet ZXing, page Barcode Contents
  https://github.com/zxing/zxing/wiki/Barcode-Contents
- QR-Code-generator : Project Nayuki, licence MIT. Cite par l'auteur de
  QRCode comme determinant dans le developpement de sa librairie
  https://www.nayuki.io/page/qr-code-generator-library

### Documentation materielle

- TF-Luna Product Manual, Benewake (`docs/Datasheet/`)
- Arduino UNO Q, fiche technique (`docs/Datasheet/`)
- Ecran LCD ILI9341, fiche technique (`docs/Datasheet/`)
- MPU-6050 Register Map and Descriptions, InvenSense. Origine des adresses
  de registres et de la sensibilite gyroscopique utilisees dans
  `sketch/imu.cpp` et `sketch/config.h`.
- HC-SR04 Ultrasonic Ranging Module, fiche technique du fabricant. Origine
  de l'impulsion de declenchement de 10 us et du facteur de conversion de
  la duree d'echo en distance.
- WS2812B Intelligent Control LED, Worldsemi. Protocole a fil unique
  800 kHz, exigence a l'origine de la version imposee de NeoPixel.
- Fichiers 3D du chassis et du PCB (`hardware/`)

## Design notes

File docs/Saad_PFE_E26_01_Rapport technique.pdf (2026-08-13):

ÉCOLE DE TECHNOLOGIE SUPÉRIEURE

UNIVERSITÉ DU QUÉBEC

RAPPORT TECHNIQUE
PRÉSENTÉ À L’ÉCOLE DE TECHNOLOGIE SUPÉRIEURE DANS LE CADRE DU PROJET DE FIN D’ÉTUDES DU BACCALAURÉAT EN GÉNIE ÉLECTRIQUE

RAPPORT TECHNIQUE FINAL

PAR
Serby Brian, BARTHELEMY
Vlad Alexandru, ILIE
Yury, ERESHCHENKO
Ryan, LEUNG
Yoan, SAPET

MONTRÉAL, LE 12 AOÛT 2026

I

REMERCIEMENTS

L'équipe tient à remercier M. Saad, professeur accompagnateur, pour son encadrement, ses

conseils techniques et sa disponibilité tout au long du projet. Nous remercions également M.

Désilets, promoteur du projet, pour sa confiance ainsi que la définition claire du mandat qui a guidé

l'ensemble de notre démarche. Enfin, nous exprimons notre gratitude envers M. Zalzal pour les

prêts de matériels et son aide technique qui ont permis de réduire les coûts du projet et d'accélérer

la phase de prototypage.

II

RÉSUMÉ

Conception d'un véhicule téléguidé autonome pour l'initiation à l'ingénierie

L'objectif de ce rapport technique consiste à documenter la conception et la réalisation d'un véhicule

téléguidé destiné à susciter l'intérêt des élèves du secondaire et du cégep au domaine de l’ingénierie. Le

Québec fait face à une pénurie croissante de main-d'œuvre technique qualifiée, avec plus de 50 000 postes

vacants prévus d'ici 2030. M. Dominik Désilets confie à l’équipe le mandat de concevoir un prototype

fonctionnel illustrant la transformation d'un objet familier, soit la voiture téléguidée, en système

d'ingénierie complexe. La solution finale doit offrir trois modes de contrôle (manuel, programmé et

autonome), une interface compréhensible en moins de 5 minutes, une précision de trajectoire de ±10 cm

et un arrêt obstacle à 10 cm maximum. Il s'agit d'un projet de fin d'études en génie électrique.

Les solutions existantes sur le marché, telles que les kits robotiques commerciaux, demeurent soit trop

coûteuses, soit trop complexes pour être reproduites et utilisées de manière autonome en milieu éducatif.

Pour résoudre ce problème, l'équipe conçoit un véhicule téléguidé de type char d'assaut chenillé, contrôlé

à distance via une interface web accessible depuis un appareil mobile.

Pour trouver la solution qui répond le mieux aux besoins du client, l'équipe génère plusieurs concepts

à l'aide d’un remue-méninge, évalués au moyen de barèmes et de matrices de décision. Les matrices

considèrent l'aspect technique, l'aspect économique, l'aspect temporel et l'aspect socio-environnemental.

À la suite de l'analyse de faisabilité, l'équipe détermine que le concept composé d'un Arduino UNO Q,

d'un châssis Hiwonder tout-en-un à chenilles métalliques, d'un capteur ultrason HC-SR04, d'un lidar TF-

Luna, d'un gyroscope MPU-6050 et d'une caméra Logitech C270 720p représente la solution la mieux

adaptée au problème. La communication s'effectue par Wi-Fi UDP/WebSocket et l'interface utilisateur

prend la forme d'une application web intégrant un système de programmation par blocs. Cette solution se

démarque par un coût total de 486,20 $, respectant la contrainte budgétaire de 500 $, une reproductibilité

assurée par des composantes disponibles chez des fournisseurs établis et une modularité facilitant la

maintenance et l'évolution du système.

Mots-clés : Véhicule téléguidé, robotique, navigation autonome, Arduino UNO Q, interface web.

III

## TABLE DES MATIÈRES

REMERCIEMENTS | I
RÉSUMÉ | II
LISTE DES TABLEAUX | VII
LISTE DES FIGURES | VIII
LISTE DES ABRÉVIATIONS, SIGLES ET ACRONYMES | IX
LISTE DES SYMBOLES ET UNITÉS DE MESURE | XI

IV

V

ANNEXE III DIAGRAMME FONCTIONNEL: SYSTÈME DE NAVIGATION AUTONOME ... 51

VI

ANNEXE V ANALYSE FINANCIÈRE | 53
ANNEXE VI MATRICES DE DÉCISION ET BARÈME DES MICROCONTRÔLEURS | 59
ANNEXE VII MATRICES DE DÉCISION ET BARÈME POUR LES DÉTECTIONS | 61
ANNEXE VIII MATRICES DE DÉCISION ET BARÈME POUR LA VISION | 63
ANNEXE IX MATRICES DE DÉCISION ET BARÈME POUR LA COMMUNICATION | 65
ANNEXE X MATRICES DE DÉCISION ET BARÈME POUR LE CHÂSSIS | 67
ANNEXE XI DIAGRAMME DE GANTT | 69
ANNEXE XII ANALYSE DES RISQUES MISE À JOUR | 71
LISTE DE RÉFÉRENCES BIBLIOGRAPHIQUES | 73

VII

LISTE DES TABLEAUX

VIII

LISTE DES FIGURES

IX

LISTE DES ABRÉVIATIONS, SIGLES ET ACRONYMES

Terme | Abréviation | Définition
Diode électroluminescente | DEL | Une diode qui émet un rayonnement lumineux non cohérent par recombinaison d’électrons et de trous lorsqu’un courant électrique continu la traverse (Diode électroluminescente, 2016).
Universal asynchronous receiver transmitter | UART | Un circuit qui assure la conversion de données parallèles en une séquence de bits transmise en série, ou vice versa (Émetteur-récepteur universel asynchrone, 1999).
Wireless Fidelity | Wi-Fi | Mode de transmission sans fil, par ondes radioélectriques, permettant la communication en réseau entre appareils qui ont obtenu la certification pertinente et qui satisfont aux normes en vigueur (Wi-Fi, 2022).
Internet des objets | IDO | Réseau formé par l’ensemble des objets connectés capables de communiquer avec des humains, mais aussi entre eux, pour collecter, transmettre et traiter des données (Internet des objets, 2025).
iPhone Operating System | iOS | L’iOS est un système d’exploitation mobile créé et développé par la société américaine Apple exclusivement pour ses produits (iOS, s.d.).
Composant monté en surface | CMS | Composant électronique pouvant être collé ou soudé sur une face ou sur les deux faces d’un circuit imprimé, ou sur un substrat céramique non percé (Composant pour montage en surface, 1994).
Universal serial bus | USB | Un type de prise (port) qui permet de brancher un périphérique à un ordinateur (USB, s.d.).
Light detection and ranging | Lidar | Capteur actif qui mesure le temps de propagation aller et retour d’un faisceau lumineux émis par un laser pour déterminer la position et la distance d’une cible par rapport à l’émetteur (Lidar, 2018).
Microcontrôleur | µC | Puce constituée d’éléments intégrés lui permettant de fonctionner comme une unité autonome, et conçue spécifiquement pour contrôler un dispositif donné (Microcontrôleur, 2021).
Modulation de largeur d’impulsion | MLI | Méthode d’encodage de l’information faisant varier la durée des impulsions (Modulation d’impulsions en durée, 1999).

X

Terme | Abréviation | Définition
Affichage à cristaux liquides | ACL | Désigne principalement les écrans qui utilisent le reflet de la lumière sur des cristaux liquides pour afficher des données alphanumériques ou des images (Écran à cristaux liquides, s.d.).
Protocole UDP | UDP | Protocole utilisant le protocole IP pour expédier des datagrammes d’une application Internet à l’autre (Protocole UDP, 2002).
General Purpose Input/Output | GPIO | Les ports GPIO sont des ports d’entrées-sorties très utilisés dans le monde des microcontrôleurs, en particulier dans le domaine de l’électronique embarquée (STMicroelectronics, 2025).
Open-Source Computer Vision Library | OpenCV | OpenCV est une bibliothèque de fonctions de programmation principalement destinée à la vision par ordinateur en temps réel (OpenCV, s.d.).
Sans objet | S.O. | Mention qui indique que la personne qui remplit un document n'est pas concernée par l'élément en question ou que ce dernier ne s'applique pas dans un cas donné.
Bus I2C | I2C | Bus série synchrone à deux fils, une ligne de données (SDA) et une ligne d'horloge (SCL), qui relie plusieurs périphériques à faible débit à un contrôleur, chaque périphérique étant identifié par une adresse (Leens, 2009)
Interface SPI | SPI | Bus série synchrone en duplex intégral fonctionnant selon un modèle maître-esclave, utilisant des lignes distinctes pour les données émises (MOSI), les données reçues (MISO), l'horloge (SCLK) et la sélection du périphérique (CS) (Leens, 2009)

XI

LISTE DES SYMBOLES ET UNITÉS DE MESURE

Grandeur / Terme | Symbole / Unité | Description
Mètre | m | Unité de base SI de longueur
Millimètre | mm | 10⁻³ m
Centimètre | cm | 10⁻² m
Seconde | s | Unité de base SI de temps
Microseconde | µs | 10⁻⁶ s
Milliseconde | ms | 10⁻³ s
Hertz | Hz | Unité SI de fréquence (1 cycle/s)
Kilohertz | kHz | 10³ Hz
Mégahertz | MHz | 10⁶ Hz
Gigahertz | GHz | 10⁹ Hz
Volt | V | Unité SI de tension électrique
Milliampère | mA | 10⁻³ A, unité de courant électrique
Milliwatt | mW | 10⁻³ W, unité de puissance
Kilobits par seconde | kbps | 10³ bits/s, débit de transmission
Mégabits par seconde | Mbps | 10⁶ bits/s, débit de transmission
Gigaoctet | Go | 10⁹ octets, capacité de mémoire
Images par seconde | fps | Cadence de capture vidéo
Mégapixel | MP | 10⁶ pixels, résolution d’image
Pixel | p | Plus petit élément d’une image (ex. : 1080p)
Degré | ° | Unité de mesure d’angle plan
Dollar canadien | CAD | Devise utilisée pour l’analyse financière
Plus ou moins | ± | Indique une tolérance ou incertitude
Pour cent | % | Proportion sur cent

INTRODUCTION

Le présent document constitue le rapport technique final du projet de fin d'études en génie électrique.

Il fait suite au rapport de proposition de projet et au rapport d'étape, et clôt le mandat confié à l'équipe.

Le Québec manque de main-d'œuvre technique qualifiée, alors que les jeunes utilisent quotidiennement

des technologies dont ils ignorent les principes. M. Dominik Désilets, coordonnateur des projets de fin d'études en génie électrique à l'École de technologie supérieure, a confié à l’équipe la conception d'un

véhicule téléguidé autonome à vocation pédagogique. Le prototype doit rendre visible le travail

d'ingénierie devant un public du secondaire et du cégep, dans les limites d'un budget de 500 $ CAD et

d'un délai de douze semaines.

Ce rapport documente la réalisation de ce prototype. Il vise une documentation suffisante pour qu'une

autre équipe qualifiée comprenne la conception et reproduise le véhicule.

Le document se divise en sept chapitres. Le chapitre 1 rappelle le contexte, la problématique et les

objectifs du projet. Le chapitre 2 décrit la méthodologie de travail et les conditions de réalisation. Le

chapitre 3 justifie le choix des outils et des technologies retenus. Le chapitre 4 constitue la documentation

technique du prototype, de l'architecture matérielle aux plans de tests. Le chapitre 5 confronte les résultats

mesurés aux objectifs initiaux. Le chapitre 6 évalue les impacts du projet sur l'environnement et sur le

bien-être des personnes. Le chapitre 7 conclut sur les leçons apprises et sur les recommandations pour la

continuation du projet. Les annexes rassemblent les diagrammes fonctionnels, les matrices de décision,

l'analyse financière, la planification et l'analyse des risques.

CHAPITRE 1

CONTEXTE, PROBLÉMATIQUE, OBJECTIFS

### 1.1 Contexte du projet

Le Québec fait face à une pénurie croissante de main-d'œuvre technique qualifiée. L'Ordre des

ingénieurs du Québec prévoit plus de 50 000 postes vacants d'ici 2030 (OIQ, 2021), tandis que le taux de

décrochage scolaire au secondaire s'établit à 14 % (ISQ, 2025). Les jeunes consomment les technologies

numériques sans en comprendre les principes sous-jacents, ce qui limite leur intérêt pour les carrières en

génie. Ce déficit d'exposition concrète compromet à long terme la capacité d'innovation du Québec et la

pérennité de ses infrastructures essentielles.

En réponse à cet enjeu sociétal, M. Dominik Désilets, coordonnateur des projets de fin d'études en génie électrique à l'ÉTS, mandate une équipe de cinq étudiants pour concevoir un véhicule téléguidé

autonome à vocation pédagogique. Le dispositif cible les élèves du secondaire et du cégep. Sa transparence

architecturale avec algorithmes décisionnels exposés, signaux lumineux programmables, trois modes de

navigation distincts transforment un véhicule téléguidé en système d'ingénierie complexe et accessible.

Trois contraintes délimitent le projet : un budget de 500 $ CAD, un délai de douze semaines et une

exigence de reproductibilité du prototype.

### 1.2 Problématique

L'absence d'outils pédagogiques concrets en robotique accessibles au niveau secondaire freine

l'attraction des jeunes vers les disciplines du génie. Les solutions commerciales existantes manquent de

transparence algorithmique et ne permettent pas aux élèves d'interagir directement avec les décisions du

système. Le projet répond à ce besoin en proposant un véhicule dont l'architecture matérielle et logicielle

est entièrement documentée et modifiable, illustrant de façon tangible les enjeux de la santé et de la

sécurité publiques liés à la robotique mobile, les compromis économiques inhérents à tout projet

d'ingénierie contraint par un budget, ainsi que les incidences environnementales associées aux systèmes

embarqués alimentés par batterie Li-Ion.

### 1.3 Objectifs

Les six objectifs suivants encadrent la réalisation du projet :

1. Concevoir un véhicule électrique téléguidé fonctionnel dans les limites d'un budget de 500 $ CAD

et d'un délai de douze semaines.

2. Susciter l'intérêt des élèves du secondaire pour le génie par l'intégration d'au moins quatre signaux

lumineux fonctionnels (clignotants, gyrophares et feux de freinage) programmables par les élèves.

3. Implémenter trois modes de contrôle distincts : manuel, programmé et autonome avec un temps

de commutation inférieur à 10 s et une fiabilité de réponse de 100 % dans un rayon de 20 m.

4. Implémenter un système de navigation intelligent assurant un suivi de trajectoire avec un écart

maximal de 10 cm et un arrêt complet à une distance maximale de 10 cm d'un obstacle.

5. Offrir une interface de contrôle intuitive compréhensible en moins de 5 minutes par un élève du

secondaire sans formation préalable.

6. Démontrer une méthodologie d'ingénierie rigoureuse conforme aux exigences académiques de l'ÉTS, incluant la traçabilité des décisions techniques et le respect des jalons du projet.

CHAPITRE 2

MÉTHODOLOGIE DE TRAVAIL

### 2.1 Modèle de développement

Le concept retenu à l'issue de la phase de conception repose sur cinq sous-systèmes : le châssis, le

microcontrôleur, le protocole de communication sans fil, la vision et la détection d'obstacles. Le présent

chapitre décrit la méthodologie employée pour en tirer un prototype fonctionnel.

L'équipe emploie une méthode de développement agile. Ce choix découle de deux caractéristiques du

projet. Le mandat initial laisse plusieurs exigences ouvertes, notamment le niveau d'autonomie visé et

l'ergonomie de l'interface. L'équipe découvre par ailleurs l'Arduino UNO Q, lancée quelques mois avant

la session, sur laquelle peu de documentation existe alors. Une méthode itérative absorbe cette incertitude

plutôt qu'une planification qui risque de figer plus loin dans le cycle de développement.

Le développement progresse par itérations de deux semaines, chacune ciblant un sous-système livrable

et testable. Une démonstration au reste de l'équipe et une rétrospective closent l'itération et ajustent la

portée de la suivante. Cette cadence expose rapidement les difficultés d'intégration. Chaque module

franchit ses essais unitaires avant son intégration au véhicule. Les critères d'acceptation découlent des

objectifs du chapitre 1 et demeurent fixés indépendamment des résultats. La section 4.6 détaille les

protocoles d'essai.

La réalisation progresse selon huit étapes : environnement de développement, approvisionnement,

modélisation 3D de la carrosserie et des supports, programmation de chaque composante, essais unitaires,

impression 3D, intégration globale, puis mesures de performance. Chaque difficulté suit une démarche

expérimentale : hypothèse, montage instrumenté, mesure, analyse et correction.

### 2.2 Planification et suivi

Le diagramme de Gantt de l'ANNEXE XI structure la planification. Il découpe la réalisation en trois

phases, identifie les jalons et met en évidence le chemin critique. Chaque tâche porte un responsable, des

dates, une durée et un effort estimé.

Le suivi repose sur un tableau Kanban sous GitHub Projects et une réunion hebdomadaire tenue sur

Teams. L'équipe y compare l'avancement réel à l'échéancier, puis redistribue la charge au besoin. Des rencontres avec le professeur superviseur et le promoteur valident périodiquement l'alignement des

orientations techniques sur le besoin du client.

Chaque membre assume la responsabilité d'un sous-système, ce qui parallélise le développement tout

en assurant l'imputabilité de chaque module.

### 2.3 Gestion de configuration

Git assure l'archivage et la traçabilité de tous les fichiers de programmation. Le dépôt du projet, hébergé

sur GitHub, réunit le micrologiciel, les modules Python, l'interface web, les fichiers de conception

mécanique et électronique ainsi que les fiches techniques des composantes. Il est accessible à l'adresse

https://github.com/YuryEr/ELE795-TankETS. Le développement s'effectue sur des branches dédiées,

fusionnées après revue par un second membre.

Le code adopte une architecture modulaire, en paires de fichiers d'en-tête et d'implémentation. Cette

organisation isole chaque module pour les essais unitaires. Elle facilite de plus la reprise du projet par une

autre équipe, exigence découlant de la contrainte de reproductibilité.

### 2.4 Conditions de réalisation

Le prototype mobilise les composantes retenues en conception : châssis Hiwonder à encodeurs, Arduino

UNO Q, caméra Logitech C270, capteur ultrasonique HC-SR04, lidar TF-Luna, centrale inertielle MPU-

6050, écran ACL, DEL CMS et concentrateurs QWIIC. Il exige également l'accès aux équipements de l'ÉTS : plaquettes d'essai, station de soudage, imprimante 3D, multimètre, oscilloscope, analyseur logique

et alimentation de laboratoire. La fabrication de la carte de circuit imprimé mobilise en outre les

installations du département de génie électrique. Un parcours d'essai instrumenté et un point d'accès Wi-

Fi complètent le banc de validation.

Sur le plan logiciel, l'environnement Arduino App Lab pilote le cœur temps réel sous Zephyr. La chaîne

Linux Debian et OpenCV assurent le traitement vidéo. L'interface repose sur HTML, CSS et JavaScript.

Git, GitHub Projects, Teams, SolidWorks pour la conception mécanique et EasyEDA Pro pour la

conception du circuit imprimé complètent l'outillage.

CHAPITRE 3

JUSTIFICATION DES OUTILS ET TECHNIQUES

La synthèse des solutions alimente le développement conceptuel du projet de véhicule téléguidé. Ce

chapitre présente les différentes solutions envisagées pour répondre aux requis du projet, en particulier

celles liées à la modularité, l’autonomie et la performance globale. Les Annexes I à III présentent les

diagrammes fonctionnels du projet.

### 3.1 Fonctions principales

Le projet regroupe deux sous-ensembles distincts. En premier lieu, le châssis comportant toutes les

parties mécaniques, dont le microcontrôleur et l’ensemble des capteurs. Puis, une interface de contrôle

servant à diriger à distance le véhicule.

Tableau 3.1 Description des fonctions principales du projet

Partie | Fonction | Description
Châssis | Traiter | Traitement des informations des différents capteurs grâce à un microcontrôleur
| Communiquer | Envoie et reçoit des informations de l’application de contrôle
| Détecter | Capter des informations grâce aux différents capteurs
| Interagir | Faire avancer le véhicule via les moteurs et interagir avec l’utilisateur via des DEL et un écran
| Alimenter | Alimenter le véhicule pour un fonctionnement sans fil
Interface de contrôle | Contrôler | Diriger le véhicule en mode manuel et choisir le type de fonctionnement
| Afficher | Donner à l’utilisateur les informations liées au véhicule, telles que l’état des DEL, des moteurs et de la détection

### 3.2 Microcontrôleur

L’équipe envisage deux architectures de traitement embarqué, chacune présentant des compromis entre

puissance de calcul, contrôle en temps réel et complexité d’intégration.

La première architecture est une architecture hybride combinant un Raspberry Pi 4 et un ESP32. Le

Raspberry Pi 4 est doté d’un processeur quad-core ARM Cortex-A72 à 1,5 GHz sous Linux (Raspberry

Pi Foundation, 2023a). Il prend en charge toute la logique haut niveau : traitement de la vision via OpenCV

(Bradski & Kaehler, 2019), exécution des algorithmes de navigation et hébergement de l’interface web.

L’ESP32, avec ses deux cœurs Xtensa LX6 à 240 MHz et FreeRTOS assure le contrôle bas niveau temps

réel : contrôle des moteurs, lecture des encodeurs, gestion des capteurs et des signaux lumineux (Espressif

Systems, 2023). La communication intercartes s’effectue via UART. Cette séparation des responsabilités

élimine les conflits de latence inhérents à un système d’exploitation généraliste pour les tâches critiques

en temps réel et constitue un patron d’architecture validé en robotique mobile (Shih, Liao et Chang, 2021).

Le coût combiné des deux cartes est d’environ 192 CAD. Le principal inconvénient de cette architecture

est la complexité d’intégration entre les deux environnements de développement.

La deuxième architecture est l’Arduino UNO Q. Celle-ci intègre sur une seule carte un

microprocesseur Qualcomm Dragonwing™ QRB2210 quad-core à 2,0 GHz sous Linux Debian et un

microcontrôleur STM32U585 dédié au contrôle temps réel grâce à Zephyr OS (Arduino, 2026). Cette

double architecture native reproduit la séparation fonctionnelle de la première architecture, mais sur une

seule carte, éliminant de ce fait la communication intercartes et simplifiant le câblage. Le MCU

STM32U585 assure ainsi le contrôle des moteurs, la lecture des encodeurs, la gestion des capteurs et des

signaux lumineux, tandis que le MPU Qualcomm prend en charge le traitement de la vision via OpenCV,

l’exécution des algorithmes de navigation et l’hébergement de l’interface web, soit l’ensemble des

fonctionnalités de la première architecture. De plus, elle possède une connectivité Wi-Fi 5 double bande

et Bluetooth 5.1 intégrées. Enfin, son prix d’environ 98 CAD est moins cher que la première architecture.

Son principal inconvénient demeure son caractère très récent.

### 3.3 Protocoles de communication sans fil pour télécommande robotique

Bluetooth Low Energy 5.0 opère sur la bande 2,4 GHz avec une consommation inférieure à 10 mW.

Sa portée typique atteint 10-40 m en intérieur. Sa latence configurable descend à 7,5 ms en mode

connexion rapide. La bibliothèque Android BluetoothLE permet l’intégration native sans infrastructure

réseau (Bluetooth Special Interest Group, 2021). Sa vulnérabilité aux interférences dans les

environnements scolaires denses constitue sa principale limite.

Wi-Fi 802.11n offre un débit UDP jusqu’à 150 Mbps avec une latence inférieure à 5 ms en réseau

local. Sa portée atteint 30-50 m en intérieur. Le UNO Q intègre nativement le Wi-Fi dual-band 2,4/5 GHz.

Un serveur WebSocket embarqué permet le contrôle en temps réel depuis une application Android

standard (IEEE, 2009).

ZigBee (IEEE 802.15.4) cible les réseaux maillés IDO basse consommation. Sa latence de 15-30 ms

et son débit de 250 kbps restent acceptables pour le contrôle de véhicule. Son intégration Android nécessite

des modules dédiés et une pile logicielle complexe. Son usage dans les projets robotiques pédagogiques

demeure marginal (ZigBee Alliance, 2015).

### 3.4 Systèmes de détection d’obstacles et de navigation autonome

Ultrasons HC-SR04 mesurent la distance par temps de vol d’une impulsion sonore à 40 kHz. La plage

de mesure couvre 2 à 400 cm avec une résolution de 3 mm. Le faisceau d’émission couvre un angle de

±15°. Le temps de cycle minimal atteint 60 ms par capteur. Ce composant présente une immunité totale à

l’éclairage ambiant et un coût unitaire de 10 à 15 CAD (ElecFreaks, s.d.). Ses angles morts latéraux et son

insensibilité aux surfaces absorbantes constituent ses principales limites.

Le lidar TF-Luna mesure la distance par temps de vol d'une impulsion infrarouge. Sa plage utile

s'étend de 20 à 800 cm, avec une précision de ±6 cm (Benewake, s.d.). Son faisceau n'éclaire que 2°. La

mesure est donc précise, mais le capteur reste aveugle à tout ce qui sort de son axe. Sa zone morte de 20

cm constitue sa seconde limite, puisqu'elle impose un seuil de décision nettement supérieur à cette valeur.

Le capteur se lit en I2C, sans pile logicielle de cartographie. Un servomoteur oriente son support pour

couvrir plusieurs directions, au prix d'environ une seconde par balayage. Ce compromis entre précision

angulaire et couverture est courant en robotique mobile (Siegwart, Nourbakhsh & Scaramuzza, 2011). Son

coût unitaire d'environ 28 CAD représente 5 % du budget total du projet.

Le capteur infrarouge Sharp GP2Y0A21YK0F mesure la distance par triangulation optique. Sa plage

couvre 10 à 80 cm et sa sortie analogique se lit sans protocole de communication (Sharp Microelectronics,

2022). Son coût unitaire d'environ 20 CAD se situe entre celui des deux autres options. Sa portée plafonne

toutefois à 80 cm, sous la distance nécessaire pour réagir à un obstacle rencontré en mouvement. Sa mesure

dépend en outre de la réflectivité de la surface visée et de l'éclairage ambiant, ce qui la rend instable en

salle de démonstration.

### 3.5 Vision

Une caméra assure la détection d’objets, la reconnaissance de feux de circulation et la navigation

autonome du véhicule (tracé et feu de circulation).

La première option est la Raspberry Pi Camera Module V2, dotée d’un capteur Sony IMX219 de 8

mégapixels supportant la capture vidéo jusqu’en 1080p à 45 fps (Raspberry Pi Foundation, 2023b). Elle

se connecte directement au port CSI du Raspberry Pi, offrant une intégration native avec OpenCV et les

bibliothèques de vision par ordinateur. Son principal inconvénient est sa dépendance exclusive au

Raspberry Pi via le câble ruban CSI, ce qui la rend incompatible avec l’Arduino UNO Q.

La deuxième option est le module Hiwonder ESP32-S3 AI Vision, basé sur le processeur dual-core

Xtensa LX7 à 240 MHz (Hiwonder, s.d.) avec une caméra intégrée de 2 mégapixels. Il supporte

nativement la transmission vidéo en temps réel via Wi-Fi, ainsi que des fonctions de reconnaissance de

visages, de couleurs et de suivi de ligne. Son avantage principal est son traitement embarqué des tâches

de vision simples. Cependant, sa résolution limitée à 2 mégapixels et sa puissance de calcul restreinte le

rendent peu adapté à des algorithmes de détection plus complexes, comme la reconnaissance de feux de

circulation.

La troisième option, Logitech C270, est une webcam USB 720p offrant une résolution 1280×720 à 30

fps avec un objectif grand angle à 90° (Logitech, s.d.) de champ de vision. Sa connexion USB prête à

l’emploi la rend compatible avec les deux architectures de contrôle envisagées Raspberry Pi 4 et Arduino

UNO Q, sans dépendance à un port propriétaire. Cette polyvalence constitue son principal avantage, car

elle peut être remplacée ou mise à niveau sans modifier l’architecture du système. Son coût d’environ 35

CAD est également le plus bas des trois options.

### 3.6 Évaluation des concepts

Les critères, la pondération et les résultats des matrices de décision ayant guidé ces choix sont présentés

aux ANNEXE VI (microcontrôleur), ANNEXE VII (détection), ANNEXE VIII (vision), ANNEXE IX

(communication) et ANNEXE X (châssis). Grâce aux matrices de décision, l’Arduino UNO Q a été

sélectionné pour sa puissance de calcul, son grand nombre de ports et sa compatibilité avec la vision par

ordinateur. Il permet l’ajout de modules et une intégration future de l’intelligence artificielle, tout en

restant fiable et simple d’utilisation. Le module à ultrasons HC-SR04 a été retenu pour la détection en

raison de sa robustesse dans divers environnements, de son faible coût et de sa facilité d’intégration.

L’équipe a pris la décision d’ajouter le lidar TF-Luna afin d’améliorer la précision des données pour la détection d’obstacle. La caméra Logitech C270 a été retenue pour sa compatibilité USB avec les deux

architectures envisagées, sa cadence de 30 images par seconde et son faible coût. Sa résolution est la plus

basse des trois options, mais elle demeure suffisante pour la détection de ligne et de feux à l'échelle d'une

salle de classe, et son interface standard permet de la remplacer sans toucher à l'architecture. Pour la

communication, le Wi-Fi UDP/WebSocket a été sélectionné pour son faible temps de latence, sa bonne

portée et sa grande compatibilité avec les principales plateformes mobiles (Android et iOS). Enfin, le

châssis tout-en-un a été retenu, car il intègre des encodeurs, une batterie et un système de recharge. Ceci

réduit ainsi la complexité et le temps d’assemblage tout en assurant de bonnes performances globales.

Le barème de l'ANNEXE VII accorde par ailleurs sa meilleure cote à un angle de couverture de 360°,

cote attribuée au TF-Luna sur la foi d'un balayage par servomoteur. Le montage réalisé ne couvre que trois

secteurs, ce que la section 5.2.4 analyse. La totalité des risques associés à ces choix technologiques,

notamment la nouveauté de l'Arduino UNO Q, est recensée et suivis à l'ANNEXE XII.

### 3.7 Solution finale

La solution retenue consiste en un robot mobile de type char d’assaut, doté d’un châssis tout-en-un

intégrant des moteurs avec encodeurs, une batterie rechargeable et un contrôleur de vitesse électronique.

Il est équipé d’une caméra Logitech C270, d’un lidar TF-Luna, d’un module à ultrasons HC-SR04 et d’un

gyroscope MPU-6050, qui permettent une navigation autonome et une détection d’obstacles fiable grâce

à une approche multicapteurs. Le véhicule est contrôlé via une interface hébergée en Wi-Fi, offrant à la

fois un pilotage en temps réel, la programmation de trajectoires et l’exécution de scénarios. Cette interface

inclut également un système de programmation par blocs, facile d’utilisation pour de futurs étudiants.

Finalement, le véhicule est muni de lumières DEL de type CMS ainsi que d’un écran ACL, servant à

interagir avec l’utilisateur et à animer le robot afin de renforcer l’engagement visuel de l’utilisateur. La

solution retenue n’intègre pas de module GPS ni de cartographie, ce qui restreint la navigation autonome

à des parcours prédéfinis et constitue une piste d’évolution future.

CHAPITRE 4

DOCUMENTATION TECHNIQUE DU PROTOTYPE

Ce chapitre documente le prototype final avec un niveau de détail permettant une reproduction du

prototype. Il présente successivement une vue d’ensemble du véhicule, son architecture matérielle et

logicielle, la liste de composantes, l’interface utilisateur, puis les procédures de tests et validation.

### 4.1 Vue d’ensemble du prototype

L’assemblage final est un véhicule chenillé télécommandé qui est capable de se déplacer selon trois

modes : pilotage manuel à distance, exécution d’une séquence programmée par blocs et navigation

autonome par suivi de ligne avec évitement d’obstacles. Le pilote le commande depuis un navigateur web,

sans installation logicielle, à partir de tout appareil compatible WI-FI. La plateforme repose sur un châssis

à chenille à suspension indépendante, surmonté d’une coque imprimée en 3D qui abrite l’électronique. Le

calcul est réparti entre deux processeurs de la carte Arduino UNO Q.

Tableau 4.1 Caractéristiques générales

Caractéristiques | Valeur
Dimensions | 194 mm x 280 mm x 290 mm
Masse totale | 2,5 kg
Type de locomotion | Chenille, entraînement différentiel, suspension à ressorts indépendante
Alimentation | Batterie au lithium 11,1 V, 6000 mAh
Autonomie approximative | 9h12min
Vitesse maximale | 1 m/s*
Type d’interface | Portail web avec écran embarqué affichant les paramètres de connexion
Mode de conduite | Manuel, programmé (blocs) et autonome (suivi de ligne avec évitement d’obstacles)

*La vitesse maximale a été mesurée selon une puissance maximale des moteurs fixée à 80 %

L’écran monté en face avant affiche le nom du réseau, le mot de passe et l’adresse de l’interface sous

forme de codes QR. Ce choix supprime toute étape de configuration côté opérateur, qui se résume à la

mise sous tension et à la lecture des codes QR.

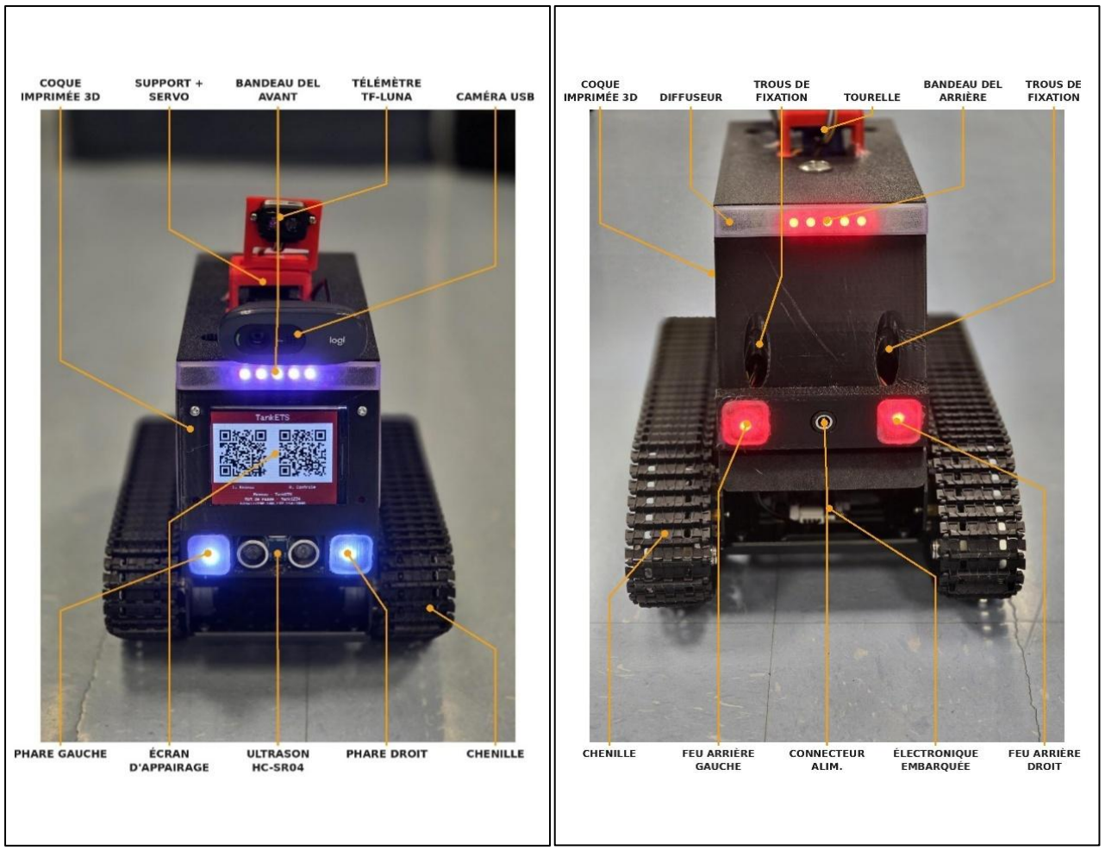
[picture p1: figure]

Figure 4.1 Véhicule complet assemblé

### 4.2 Architecture matérielle

### 4.2.1 Le circuit

Le montage compte une seule carte de circuit imprimé, conçue pour recevoir l'Arduino UNO Q. Les

périphériques ne s'y montent pas. Chacun est relié par câblage. Un fusible de trois ampères protège

l'ensemble du circuit. L'équipe conçoit la carte avec EasyEDA Pro, de la capture du schéma jusqu'au routage, puis la fait fabriquer au département de génie électrique de l'ÉTS. Recourir aux installations de l'École supprime le délai et le coût d'une commande externe, contrainte déterminante dans un projet de

douze semaines.

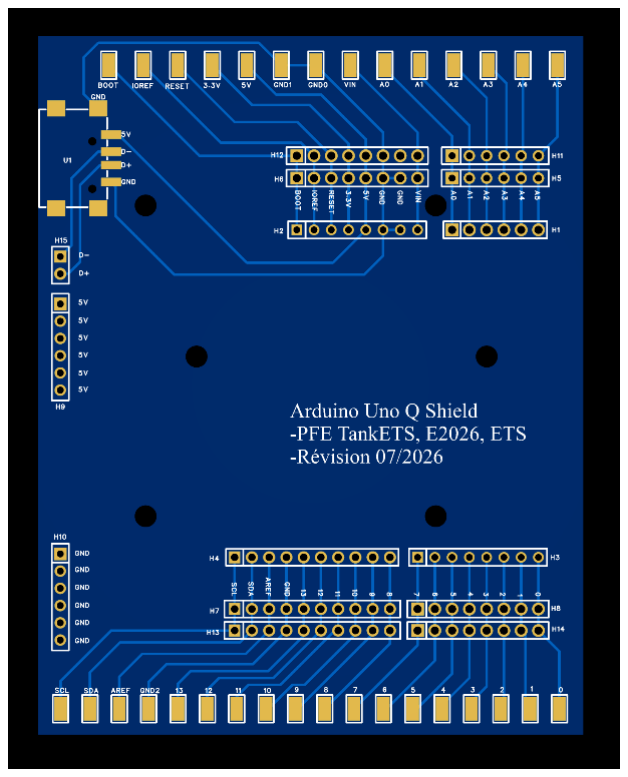
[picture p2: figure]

Figure 4.2 Circuit imprimé réalisé

### 4.2.2 Alimentation

La source d’alimentation principale est une batterie rechargeable au lithium de 11,1 V et de 6000 mAh.

La distribution électrique se divise en trois tensions distinctes : 11,1 V, 5 V et 3,3 V. La consommation

mesurée s’établit à 350 mA au repos et à 650 mA avec les moteurs et les DEL en fonction. Cette dernière

valeur fixe l’autonomie approximative à 9 h 12 min.

Le tableau 4.2 résume la tension d’opération de chaque composante.

Tableau 4.2 Tensions et sources d’alimentation des composantes

Composante | Tension (V) | Courant nominal (A) | Source
Moteur encodeur Hiwonder (individuellement) | 11,1 | 0,1 | Batterie 11,1 V
Arduino UNO Q | 11,1 | 3 | Batterie 11,1 V
Caméra Logitech C270 | 5 | 0,5 | Convertisseur abaisseur de tension 5 V
Ultrason HC-SR04 | 5 | 0,015 | Convertisseur abaisseur de tension 5 V
LIDAR TF-Luna | 5 | 0,15 | Convertisseur abaisseur de tension 5 V
DEL WS2812B | 5 | 0,049 | Convertisseur abaisseur de tension 5 V
Écran LCD | 5 | 0,12 | Convertisseur abaisseur de tension 5 V
Gyroscope MPU-6050 | 3,3 | 0,005 | Port 3,3 V de l’Arduino UNO Q
Servo moteur | 5 | 0,63 | Convertisseur abaisseur de tension 5 V

### 4.2.3 Communication

Afin de privilégier la modularité, la plupart des périphériques communiquent en I2C.

Tableau 4.3 Communication des périphériques

Lien | De | Vers | Protocole | Adresse/port
Contrôle moteur | Arduino UNO Q | Carte moteur Hiwonder | I2C | 0x34
Positionnement | MPU6050 | Arduino UNO Q | I2C | 0x68
Caméra | Logitech C270 | Arduino UNO Q | USB 2.0 | S.O.
Ultrason | HC-SR04 | Arduino UNO Q | GPIO | D2, D3

Lien | De | Vers | Protocole | Adresse/port
Lidar | TF-Luna | Arduino UNO Q | I2C | 0x10
DEL | Arduino UNO Q | WS2812B | GPIO | D6, D7
Écran LCD | Arduino UNO Q | TFT ILI9341 | SPI | D10, D8, D9, D11, D13, D12
Linux à Zephyr OS | Microcontrôleur (STM32U585) | Microprocesseur (Qualcomm Dragonwing QRB2210) | Arduino Bridge (RPC) | S.O.
Servo moteur | Arduino UNO Q | Servo SG90 | GPIO | D5

Pour simplifier les branchements, tous les modules I2C utilisent l’écosystème Qwiic dont l’Arduino

UNO Q dispose déjà d’un connecteur. Cet écosystème conserve la flexibilité du I2C tout en facilitant son

intégration, grâce à des câbles préfabriqués munis d’un connecteur JST à quatre broches. La figure 4.3

illustre les détails de ce connecteur (SparkFun Electronics, s.d.).

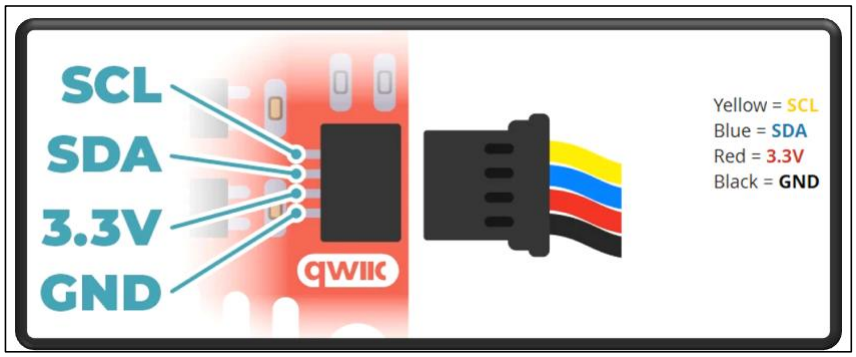
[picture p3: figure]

Figure 4.3 Connecteur Qwiic

L’équipe emploie un concentrateur QWIIC qui divise le port du microcontrôleur en plusieurs entrées.

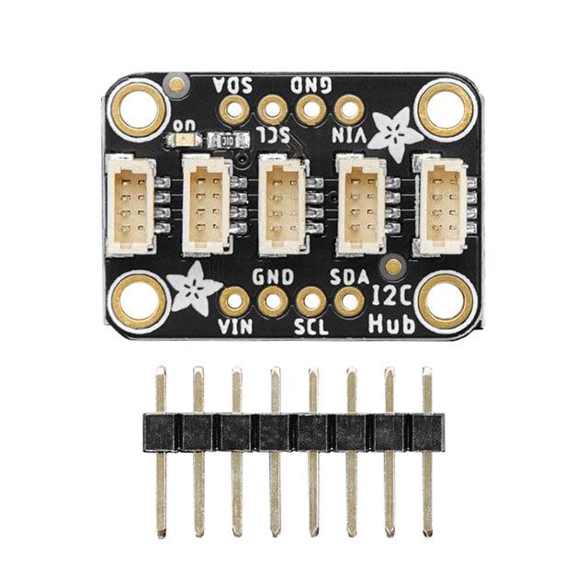
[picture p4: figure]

Figure 4.4 Concentrateur Qwiic

L’Arduino UNO Q ne supporte pas l’alimentation de la caméra via son port USB-C lorsqu’il est lui-

même alimenté par son port Vin. Une source de tension externe résout ce problème. Ceci est illustré

dans le circuit de la figure 4.5 :

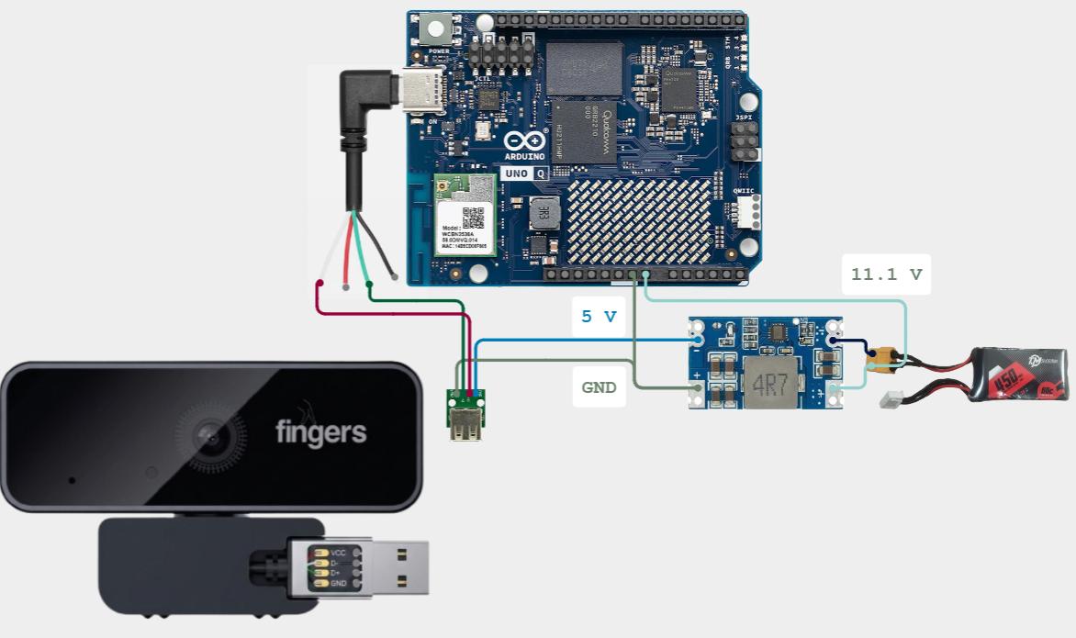
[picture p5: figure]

Figure 4.5 Circuit d’alimentation de la caméra

### 4.2.4 Le châssis

La base du véhicule est en alliage d’aluminium et pèse 1,4 kg avec les moteurs et la carte de gestion

des encodeurs. Les deux moteurs se raccordent à la carte de gestion Hiwonder, qui assure leur alimentation

et la lecture des deux voies d'encodeur. Le microcontrôleur lui déclare au démarrage le type de moteur et

la polarité de comptage des encodeurs, deux registres sans lesquels les distances mesurées sont fausses ou

de signe inverse. Le brochage des connecteurs et la signification de ces registres sont propres à cette carte.

La fiche technique du fabricant, dans le dépôt du projet, en donne le détail et doit être consultée avant le

montage. Ce prototype dispose de deux moteurs développant chacun un couple de 0,15 N.m et une vitesse

maximum de 160 tr/min. La motorisation est de type chenille permettant au châssis d’affronter n’importe

quel terrain.

### 4.2.5 La coque

La coque est modélisée sur SolidWorks 2025. Son profil affiné contient et supporte toutes les

composantes du véhicule tout en restant attrayant sur le plan esthétique. L’impression 3D se fait sur une

Bambu Lab P1S avec deux filaments. Les fenêtres et les diffuseurs des DEL ont été imprimés en PLA

transparent violet, le cockpit principal en PLA noir. Les figures 4.6, 4.7 ainsi que 4.8 sont des extraits de

l’assemblage :

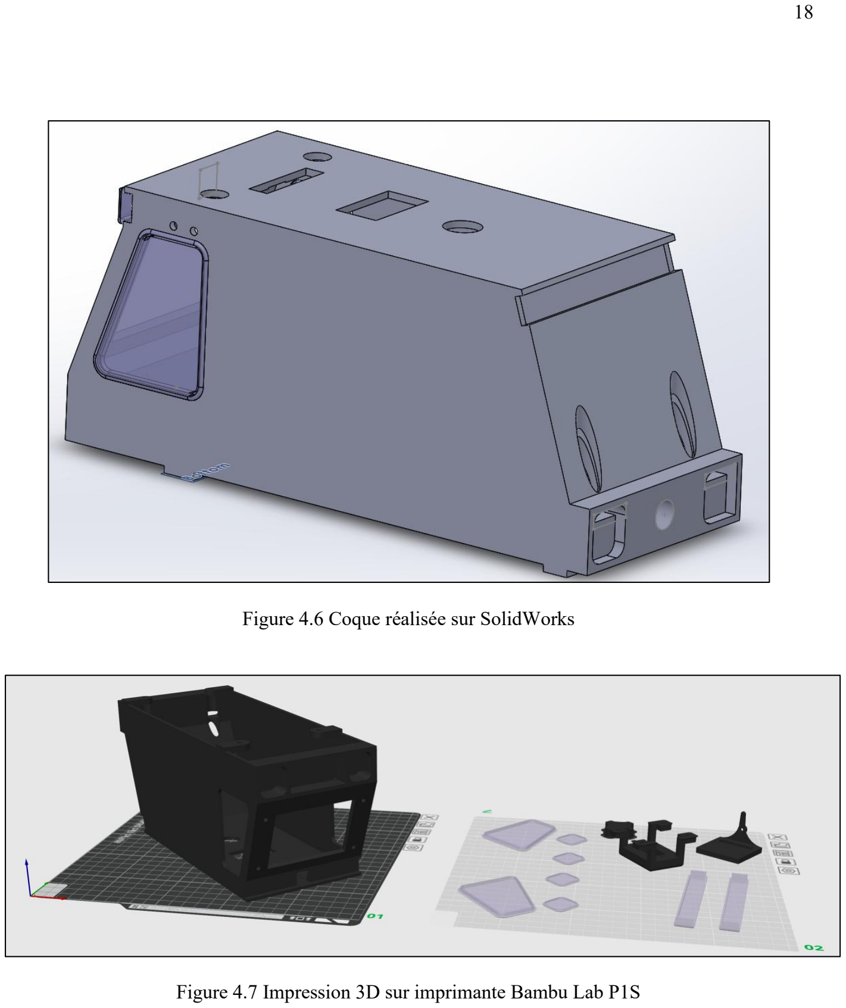
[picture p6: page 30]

Figure 4.6 Coque réalisée sur SolidWorks

Figure 4.7 Impression 3D sur imprimante Bambu Lab P1S

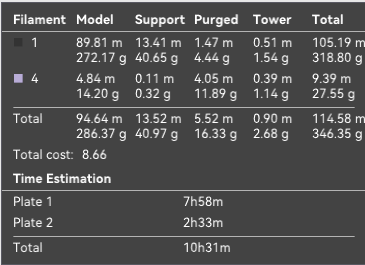
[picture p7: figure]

Figure 4.8 Ressources d’impression

### 4.3 Architecture logicielle

### 4.3.1 Configuration de l'application

L'application est structurée selon le modèle d'une Arduino App, exécutable par l'environnement Arduino

App Lab. Un fichier de configuration, app.yaml, déclare les métadonnées de l'application ainsi que le port

réseau exposé par le serveur web, soit le port 7000. Le code se répartit en deux cibles, une par processeur.

Le dossier sketch/ contient le micrologiciel C++ téléversé sur le microcontrôleur STM32U585, tandis que

le dossier python/ regroupe le serveur et les modules de vision exécutés par le microprocesseur Qualcomm

sous Linux. Les ressources statiques de l'interface web, soit les fichiers HTML, CSS et

JavaScript, résident dans le dossier assets/.

Le déploiement s'effectue en une seule commande depuis App Lab. Celle-ci compile le micrologiciel, le

téléverse sur le microcontrôleur, puis démarre le conteneur applicatif qui héberge le serveur Python. Les

dépendances Python, soit Flask, Flask-SocketIO, eventlet et OpenCV, sont installées au premier

lancement. Cette organisation isole les deux environnements d'exécution tout en les déployant

conjointement, ce qui facilite la reprise du projet par une équipe future.

### 4.3.2 Chaîne de commande

Le pilotage traverse quatre couches. Le navigateur émet un événement Socket.IO. Le serveur Python

le reçoit sur le MPU Qualcomm. Il relaie la consigne au MCU STM32U585 par le pont RPC Arduino, en

encodage MessagePack. Le MCU transmet enfin la consigne de vitesse à la carte moteur Hiwonder, en

I2C sur le bus Wire1.

Cette répartition découle du partage matériel décrit à la section 4.1. Le MPU orchestre, le MCU exécute.

Le serveur ne calcule aucune consigne moteur. Il transmet des grandeurs de haut niveau : position du

joystick, distance en mètres, angle en degrés. Le MCU convertit ces grandeurs en commandes de vitesse

et surveille leur exécution. La carte Hiwonder génère la modulation de largeur d'impulsion en interne.

### 4.3.3 Mode manuel

Le client échantillonne le joystick toutes les 50 ms, soit 20 Hz. Il émet un couple de coordonnées

normalisées sur l'intervalle [-1, 1]. Le relâchement du joystick déclenche l'émission d'un couple nul.

Le serveur relaie les deux coordonnées au MCU sans traitement. Le mixage différentiel s'effectue sur

le MCU :

gauche = (y - x) × VITESSE_JOYSTICK

droite = (y + x) × VITESSE_JOYSTICK

Le gain de mixage vaut 80. L'interface borne la poignée du joystick à un cercle, afin que les deux axes

n'atteignent jamais leur maximum en même temps. Les consignes résultantes culminent autour de 113 en

valeur absolue. La fonction d'écriture les ramène ensuite à 100, ce qui plafonne la vitesse en pilotage

manuel et répond à la contrainte de sécurité en démonstration scolaire.

Le serveur ignore toute commande de joystick pendant l'exécution d'une séquence ou en suivi de ligne.

Cette garde écarte les conflits de consigne entre les modes.

Le système ne comporte aucun délai de garde sur la liaison. Le MCU conserve la dernière consigne

reçue en l'absence de nouvelle trame. La section 5.2 analyse cette limite.

### 4.3.4 Mode programmé

Le client sérialise la séquence en un tableau d'objets JSON. Chaque objet porte un identifiant de

commande et sa valeur. Les commandes de déplacement s'expriment en mètres, les rotations en degrés,

les attentes en secondes.

Le serveur exécute la séquence dans une tâche d'arrière-plan. Il parcourt les blocs séquentiellement.

Les commandes lumineuses s'exécutent immédiatement. Les commandes de mouvement bloquent la

progression jusqu'à leur achèvement.

Le blocage s'effectue côté Python uniquement. Le MCU exécute chaque mouvement dans une machine

à états non bloquante, rafraîchie à chaque tour de boucle. Le serveur sonde le drapeau d'activité du MCU

toutes les 200 ms. Il confirme d'abord le démarrage sous 1,5 s, puis attend la fin sous un garde-fou de 10

s. Cette architecture libère le MCU pour la surveillance des capteurs pendant le mouvement.

Le MCU asservit la distance sur les encodeurs. Il mémorise la position initiale, commande les deux

moteurs à vitesse constante, puis intègre le déplacement :

circonférence = (DIAMETRE_ROUE_MM / 1000) × π

mètres = (impulsions / IMPULSIONS_PAR_ROUE) × circonférence

Une roue de 65 mm développe une circonférence de 0,2042 m. Le train épicycloïdal produit 2200

impulsions par tour de roue, soit environ 10 774 impulsions par mètre. Le MCU stoppe les moteurs dès

l'atteinte de la distance cible, ou après 12 s.

Le MCU pivote sur place, chenilles en sens opposés. Il asservit l'angle sur le gyroscope MPU-6050

plutôt que sur les encodeurs, le patinage des chenilles faussant toute estimation odométrique en rotation.

Le MCU intègre la vitesse angulaire, plafonnée à 50 ms par pas pour écarter les sauts d'échantillonnage.

Il réduit la vitesse de moitié dans les 20 derniers degrés, puis stoppe 10° avant la cible. Cette marge

compense l'inertie du véhicule.

Les deux mouvements reposent sur un contrôleur à seuil, non sur un correcteur PID. La vitesse demeure

constante en boucle ouverte. Seule la condition d'arrêt s'asservit sur la mesure. Ce choix suffit aux vitesses

retenues et évite le réglage de gains, hors du budget temporel du projet.

Pour le retour d’état, le serveur émet le bloc courant, son rang et le total après chaque transition.

L'interface affiche cette progression. Le bouton d'arrêt lève un drapeau que toutes les boucles d'attente

testent. Le serveur commande alors l'arrêt moteur et abandonne la séquence au bloc courant. Un bloc de

nettoyage garantit l'arrêt des moteurs à la sortie, y compris sur erreur.

### 4.3.5 Mode autonome

Le mode autonome est le seul des trois modes où le véhicule établit ses propres consignes. Trois

capteurs y contribuent, avec des rôles distincts. La caméra fournit la consigne de direction et l'état des

feux de signalisation. Le capteur ultrasonique et le lidar fournissent la distance frontale. Ils sont les seuls

autorisés à interrompre le mouvement.

La répartition entre les deux processeurs suit celle de la section 4.1. Le MPU traite l'image, le MCU

traite la télémétrie. Le traitement d'image exige Linux, OpenCV et l'accès à la caméra USB. La lecture des

capteurs de distance exige au contraire un cadencement déterministe, que le noyau temps réel garantit et

que Linux ne garantit pas. Les paramètres de perception figurent au tableau 4.4.

Tableau 4.4 Paramètres de perception et de navigation autonome

Catégorie | Paramètre | Valeur | Signification
Ultrason | ULTRASON_DISTANCE_MAX | 100 cm | Portée utile, valeur plafond signifiant voie dégagée
Ultrason | ULTRASON_PERIODE_MS | 100 ms | Cadence de mesure
Lidar | LIDAR_FORCE_MIN | 100 | Seuil de rejet du signal faible
Lidar | LIDAR_DISTANCE_MIN | 20 cm | Zone morte déclarée par le fabricant
Lidar | LIDAR_DISTANCE_MAX | 800 cm | Portée fiable
Obstacle | OBSTACLE_SEUIL_CM | 25 cm | Distance de déclenchement du veto
Obstacle | OBSTACLE_ECART_SONDAGE_DEG | 45 ° | Écart des secteurs sondés

Catégorie | Paramètre | Valeur | Signification
Obstacle | OBSTACLE_STABILISATION_MS | 40 ms | Attente après l'arrivée du servomoteur
Obstacle | ULTRASON_RECUL_CM/LIDAR_RECUL_CM | 0/5 | Recul de chaque capteur par rapport au pare-chocs
Évitement | EVITEMENT_ANGLE_DEG | 45 ° | Rotation d'écartement et de remise parallèle
Évitement | EVITEMENT_ANGLE_RETOUR_DEG | 20 ° | Rotation finale vers la ligne
Évitement | EVITEMENT_DISTANCE_M | 0,45 m | Diagonale d'écartement
Évitement | EVITEMENT_LONGEMENT_M | 0,20 m | Segment parallèle à la ligne
Évitement | EVITEMENT_ESSAIS_MAX | 3 | Sondages avant abandon de la manœuvre
Suivi de ligne | VITESSE_BASE | 15 | Vitesse des deux chenilles en ligne droite
Suivi de ligne | KP_LATERAL / KD_LATERAL | 0,015/0,035 | Gains proportionnel et dérivé
Suivi de ligne | ZONE_MORTE_PX | 35 px | Écart en deçà duquel la ligne est jugée centrée
Suivi de ligne | PIXELS_MIN_LIGNE | 800 px | Seuil de déclaration d'absence de ligne
Suivi de ligne | MISS_MAX | 8 cycles | Cycles sans ligne avant l'arrêt
Vision | Résolution de capture | 640 × 360 à 30 img/s | Format de capture de la caméra
Vision | TAILLE_INFERENCE | 256 px | Côté de chaque fenêtre soumise au modèle
Vision | SEUIL_CONFIANCE | 0,40 | Seuil de rétention d'une détection
Vision | PERIODE_LIGNES/ PERIODE_INFERENCE | 0,10 s / 0,30 s | Cadences des deux boucles de vision

Catégorie | Paramètre | Valeur | Signification
Vision | REBOND_ACTIVATION/_DESACTIVATION | 2 / 4 | Cycles requis pour déclarer un feu présent ou disparu

### 4.3.5.1 Suivi de ligne par caméra

Le suivi de ligne s'exécute sur le MPU. La caméra capture en 640 × 360 à 30 images par seconde, et le

module de vision n'analyse que les 40 % inférieurs de l'image, soit le sol immédiatement devant le

véhicule.

Le principe tient en deux temps : repérer où passe la ligne noire par rapport au centre de l'image, puis

ramener le véhicule vers elle. Le module distingue d'abord la ligne du plancher par un seuillage adaptatif

(Open Source Vision Foundation, s.d.), dont le point de basculement s'ajuste localement au lieu de rester

le même sur toute l'image. Un seuil unique perdrait la ligne dès qu'une ombre traverse le champ. Un

filtrage écarte ensuite les taches isolées, opération issue de la morphologie mathématique (Serra, 1982).

Le module calcule enfin la position moyenne des pixels sombres retenus, au moyen des moments de

l'image (Hu, 1962). L'écart entre cette position et le centre de l'image, exprimé en pixels, est la seule

grandeur transmise au reste du système. Sous 800 pixels sombres, le module déclare l'absence de ligne

plutôt que de mesurer un écart sur du bruit.

Le module de navigation transforme cet écart en consignes de roues. La stratégie retenue est un correcteur proportionnel-dérivé, approche courante en robotique mobile (Åström & Murray, 2008) : la

correction répond à l'écart, mais aussi à sa vitesse de variation.

gauche = VITESSE_BASE + correction

droite = VITESSE_BASE − correction

Le second terme est indispensable ici. La boucle de vision tourne à 10 Hz et le pont RPC ajoute sa

latence. Sans lui, la correction arrive alors que l'écart a déjà changé de signe. Le véhicule oscille alors d'un

bord à l'autre jusqu'à perdre la ligne. Une zone morte de 35 pixels l'empêche par ailleurs de frétiller en

ligne droite. La correction est enfin bornée de façon à garder les deux chenilles en marche avant : le

véhicule se recentre en ralentissant une chenille, jamais en l'inversant.

Après huit cycles consécutifs sans ligne, soit environ 0,8 s, le module arrête les moteurs. Les gains

s'expriment en unités de vitesse par pixel d'écart, si bien qu'un changement de résolution de capture impose

de les reprendre.

### 4.3.5.2 Détection des feux de signalisation

La détection des feux s'exécute également sur le MPU. Le module s'appuie sur le modèle YOLOv8n

(Jocher et al., 2023), exécuté par ONNX Runtime (Microsoft, 2021). Ce modèle reconnaît les objets du

jeu de données COCO (Lin et al., 2014), dont la classe « traffic light ».

La difficulté centrale tient à la taille d'entrée du modèle, figée à 256 pixels de côté. Réduire l'image

complète à ce format divise la largeur apparente des objets par plus de deux : un feu de 6 cm vu à 1 m

passe d'environ 33 pixels à 13, sous le seuil à partir duquel le modèle le reconnaît de façon fiable. Le feu

n'était donc vu qu'au dernier moment. La stratégie retenue consiste à ne plus réduire l'image, mais à y

prélever deux fenêtres de 256 pixels de côté, aux bords gauche et droit de la partie haute. Le feu y conserve

sa taille réelle, ce qui devrait doubler la portée de détection sans avoir à réentraîner ni à réexporter le

modèle. Deux fenêtres suffisent, le feu bordant la chaussée sans jamais apparaître au centre du champ. La

méthode laisse en contrepartie une bande centrale de 128 pixels non analysée et impose deux inférences

par cycle. Les deux fenêtres se recouvrant parfois, un tri final ne conserve qu'une seule zone par feu

(Neubeck et Van Gool, 2006).

Le modèle localise le feu mais n'en donne pas la couleur. Celle-ci est déterminée ensuite, en comptant

les pixels de la zone détectée qui tombent dans trois plages de couleur. La plus représentée l'emporte. Ces

plages sont définies dans l'espace HSV (Smith, 1978), qui sépare la teinte de la luminosité et rend ainsi la

classification stable sous un éclairage variable. Le rouge occupe deux plages plutôt qu'une, cette teinte se

trouvant à la fois au début et à la fin de l'échelle.

Un filtre écarte les détections isolées : deux cycles consécutifs sont requis pour déclarer un feu présent,

quatre pour le déclarer disparu. L'asymétrie est volontaire, puisque perdre brièvement un feu qui existe est

plus risqué que d'en signaler un de trop.

L'inférence tourne à 3,3 Hz, contre 10 Hz pour le suivi de ligne, et dans une boucle distincte. Sans cette

séparation, la cadence de correction de trajectoire dépendrait du coût de l'inférence, plusieurs centaines de fois supérieur à celui de la détection de ligne. La cadence réduite reste sans conséquence : l'état d'un feu

change lentement, alors que la trajectoire exige une correction continue.

Le MPU transmet l'état du feu au MCU, qui l'intègre à son veto de sécurité. Le rouge et le jaune

imposent tous deux l'arrêt, puisque devant un feu sur le point de changer, s'arrêter est le comportement

attendu. Une détection non rafraîchie expire au bout de 3 s, faute de quoi une perte de la liaison de vision

immobiliserait le véhicule indéfiniment. La section 5.2.1 analyse la portée de détection atteinte.

### 4.3.5.3 Détection d'obstacles par télémétrie

Deux capteurs mesurent la distance frontale, et leurs faiblesses sont complémentaires (Siegwart,

Nourbakhsh & Scaramuzza, 2011). Le HC-SR04 émet une salve sonore et mesure le temps que met l'écho

à revenir (ElecFreaks, s.d.). Son faisceau couvre un cône large : il signale qu'un obstacle se trouve devant,

sans en préciser la direction. Le TF-Luna éclaire au contraire un faisceau de 2° (Benewake, s.d.). Il mesure

précisément un point, mais reste aveugle à ce qui sort de son axe. Un lidar seul manquerait un obstacle

décalé de quelques degrés. Un capteur à ultrasons seul ne donnerait qu'une distance grossière.

Le MCU interroge les deux capteurs à 10 Hz. Il ramène d'abord chaque mesure au pare-chocs avant,

les deux capteurs n'étant pas montés au même endroit sur la coque : sans ce recalage, la fusion comparerait

deux distances prises depuis deux origines différentes. Il retient ensuite la plus petite des mesures valides.

Cette règle du minimum privilégie la sécurité, puisqu'une cible vue par un seul des deux capteurs suffit à

la signaler.

Le seuil de détection est fixé à 25 cm. Il doit demeurer nettement au-dessus de la zone morte de 20 cm

du lidar, en deçà de laquelle le fabricant déclare la mesure non fiable. Placé à cette frontière même, le seuil

faisait basculer la distance frontale d'un capteur à l'autre au point exact du déclenchement, et l'obstacle

était détecté deux fois selon l'angle d'approche.

Un servomoteur oriente le support du lidar sur trois secteurs, à −45°, 0° et +45°. Ce sondage ne sert pas

à détecter l'obstacle, ce que la mesure frontale fait déjà, mais à choisir de quel côté le contourner. Il n'existe

pas de balayage permanent : le faisceau est trop étroit pour relever l'environnement en un temps

raisonnable. Le sondage ne s'exécute donc qu'une fois le véhicule immobilisé devant l'obstacle, et dure

environ une seconde. Pendant sa durée, la mesure du lidar est écartée de la distance frontale, le faisceau ne pointant plus vers l'avant. Le côté retenu ouvre la manœuvre de contournement. Le véhicule décrit un

trapèze. Il pivote de 45° vers ce côté, avance de 45 cm en diagonale pour s'écarter de la ligne, reprend un

cap parallèle, dépasse l'obstacle sur 20 cm, puis pivote de 20° vers la ligne. Chaque étape est séparée par

un arrêt complet.

### 4.3.6 Sélection et coexistence des modes

Le véhicule offre trois modes de conduite : manuel, programmé et autonome. L'implémentation les

répartit sur deux mécanismes distincts.

Un sélecteur bascule entre pilotage manuel et suivi de ligne autonome. Le serveur transmet le mode

retenu au MCU, puis active ou désactive le module de navigation. La désactivation réinitialise les variables

d'état du correcteur et arrête les roues. Le mode conditionne également les protections : le MCU n'applique

le veto d'obstacle et l'évitement qu'en mode autonome. Le pilotage manuel confie la responsabilité à

l'opérateur. Le veto ne bloque que les avances. Les rotations et la marche arrière demeurent autorisées,

puisque ce sont les manœuvres qui dégagent le véhicule.

Le mode programmé procède différemment. Un bouton d'exécution déclenche la séquence,

indépendamment du sélecteur. Cette conception découle du caractère transitoire du mode : la séquence

occupe le véhicule pour une durée finie, puis rend la main au mode courant. Un drapeau d'exécution assure

l'exclusion mutuelle avec le pilotage manuel, le serveur ignorant toute commande de joystick pendant une

séquence.

### 4.3.7 Constantes de calibration

Le tableau 4.5 recense les constantes déterminant le comportement des trois modes. Leur modification

suffit à adapter le prototype à un autre châssis ou à d'autres roues.

Tableau 4.5 Constantes de calibration du contrôle de déplacement

Catégorie | Constante | Valeur | Signification
Mécanique | DIAMETRE_ROUE_MM | 65,0 mm | Diamètre de la roue motrice
Mécanique | IMPULSIONS_PAR_TOUR | 44 | Impulsions d'encodeur par tour de moteur

Catégorie | Constante | Valeur | Signification
Mécanique | RATIO_REDUCTEUR | 50 | Rapport de réduction du train épicycloïdal
Mécanique | IMPULSIONS_PAR_ROUE | 2200 | Impulsions par tour de roue (44 × 50) ≈ 10 774 impulsions/m
Vitesse | VITESSE_JOYSTICK | 80 | Sensibilité unique du pilotage manuel, appliquée linéairement aux deux axes
Vitesse | VITESSE_DEPLACEMENT | 12 | Consigne moteur en avance programmée
Vitesse | VITESSE_ROTATION | 11 | Consigne moteur en rotation programmée
Rotation | ROT_MARGE_ARRET_DEG | 10,0° | Marge d'arrêt anticipé compensant l'inertie
Rotation | ROT_MARGE_LENTE_DEG | 20,0° | Seuil de passage à demi-vitesse
Gyroscope | SENSIBILITE_GYRO | 131,0 LSB/(°/s) | Sensibilité du MPU-6050, pleine échelle ±250 °/s
Gyroscope | DLPF_20HZ | 20 Hz | Bande passante du gyroscope, filtre passe-bas
Déplacement | AVANCE_TRIM_NUM/_DEN | 5 / 16 | Compensation de dérive en ligne droite, en fraction d'unité de consigne
Déplacement | REEMISSION_MOTEUR_MS | 100 ms | Répétition de la consigne pendant un mouvement asservi
Sécurité | TIMEOUT_AVANCE_MS | 12 000 ms | Délai maximal d'une commande d'avance
Sécurité | TIMEOUT_ROTATION_MS | 8 000 ms | Délai maximal d'une commande de rotation
Réseau | PORT_WEB | 7000 | Port du serveur d'interface et du flux vidéo
Réseau | INTERVALLE_MS | 50 ms | Période d'émission du joystick (20 Hz)
Réseau | RESEAU_SSID / RESEAU_IP | VTA/10.42.0.1 | Point d'accès créé par la carte, valeurs fixées à la compilation
Bus I2C | ADRESSE_MOTEUR | 0x34 | Carte de contrôle moteur Hiwonder
Bus I2C | ADRESSE_GYRO | 0x68 | Centrale inertielle MPU-6050

Catégorie | Constante | Valeur | Signification
Bus I2C | ADRESSE_LIDAR | 0x10 | Lidar TF-Luna

### 4.4 Interface utilisateur

### 4.4.1 Description de l’interface

L'interface utilisateur est une application web, accessible depuis n'importe quel navigateur, sur

ordinateur comme sur téléphone intelligent. Le seul prérequis est que l'appareil soit connecté au même

réseau que l'Arduino UNO Q. Elle se compose de deux onglets, un onglet de pilotage et un onglet de

programmation, consacrés respectivement au pilotage du véhicule et à la programmation par blocs.

L'onglet de pilotage réunit trois zones. Au centre s'affiche le flux vidéo de la caméra, qui permet de suivre le déplacement du véhicule à distance et d'adopter son point de vue. À droite, un joystick dirige le

véhicule en mode manuel. À gauche, quatre groupes de boutons commandent le reste des fonctions. Le

premier sélectionne le mode de conduite, manuel ou autonome. Le deuxième allume ou éteint la caméra.

Le troisième pilote les deux bandeaux de DEL supérieurs : il les allume ou les éteint et bascule leur mode

d'éclairage, feux de position ou gyrophare. Le dernier commande les phares. La figure 4.9 présente cet

onglet.

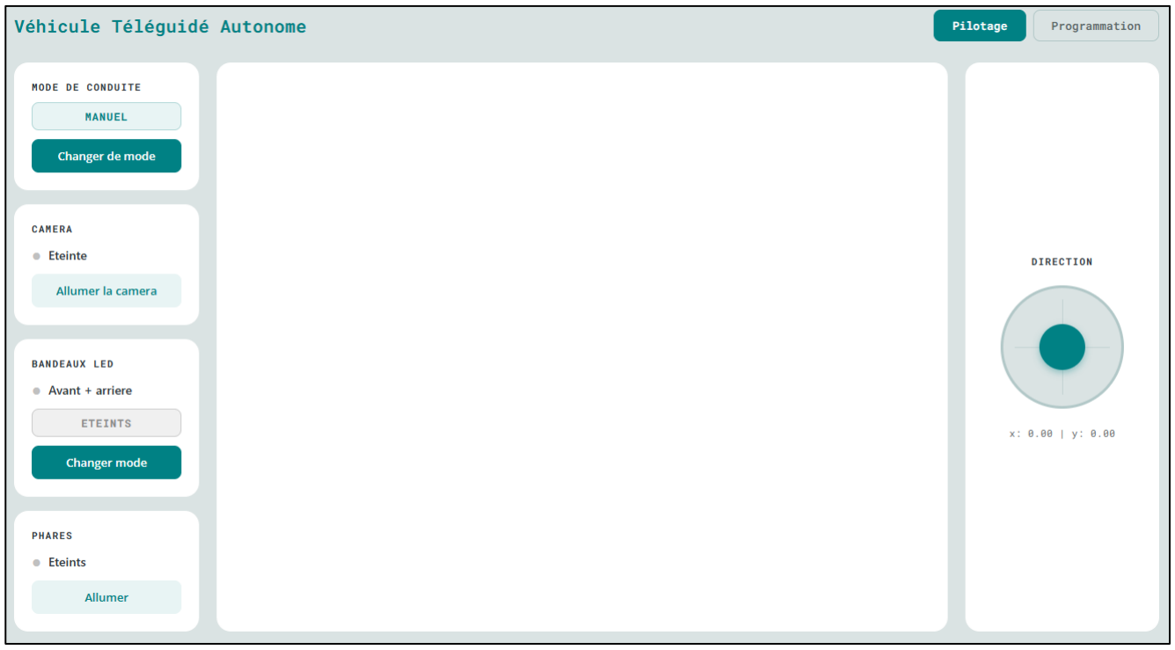
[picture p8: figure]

Figure 4.9 Onglet pilotage de l’interface utilisateur

Le second onglet est celui de la programmation par blocs. L'utilisateur y assemble une séquence de

déplacements sans écrire de code. La colonne de gauche liste les blocs disponibles :

- Avancer de x m
- Reculer de x m
- Tourner à gauche de xx °
- Tourner à droite de xx °
- Bandeaux : éteints, feux de position ou gyrophare
- Allumer ou éteindre les phares
- Attendre xx s

La zone centrale sert à composer le programme, et la colonne de droite regroupe les boutons d'exécution

et d'arrêt, surmontés d'une fenêtre qui indique le bloc en cours d'exécution. La composition est simple :

l'utilisateur glisse le bloc voulu dans la zone centrale, en règle la valeur, puis imbrique le bloc suivant. Un

signal sonore confirme l'emboîtement. Par exemple, pour faire avancer le véhicule de 5 m puis tourner de

45° à droite, il glisse d'abord le bloc « avancer de x m », y imbrique le bloc « tourner à droite de xx ° », puis saisit les valeurs 5 et 45. Le bouton d'exécution lance alors la séquence, qui se déroule

automatiquement. Pour repartir de zéro, l'utilisateur vide la zone à l'aide de la corbeille, en bas à droite.

La figure 4.10 présente cet onglet.

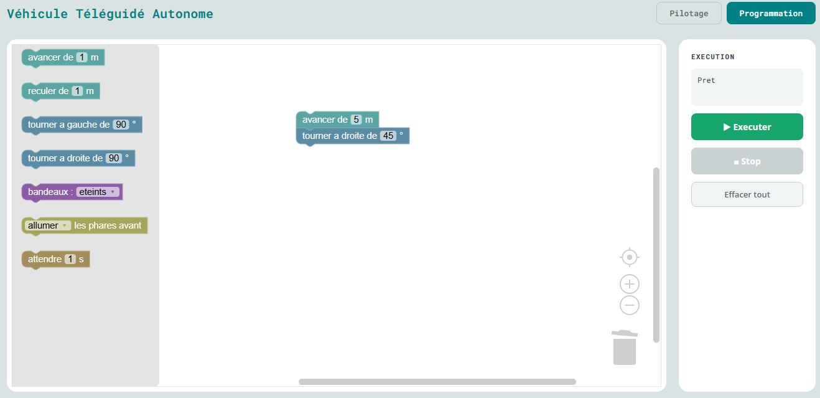
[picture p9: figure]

Figure 4.10 Onglet Programmation de l’interface utilisateur

### 4.4.2 Bibliothèques et outils logiciels utilisés

L'interface web repose sur plusieurs bibliothèques et outils libres, tant du côté serveur que du côté

client. Cette section décrit chacun d'eux, son origine et son rôle dans le projet.

Côté serveur :

- Flask : micro-cadriciel web pour Python développé par Pallets Projects (Pallets Projects, s.d.). Il

gère les routes HTTP de l'interface, soit la page principale de l'application et la route dédiée au

flux vidéo.

- Flask-SocketIO : extension de Flask créée par Miguel Grinberg (Grinberg, s.d.), qui ajoute la

prise en charge du protocole Socket.IO. Elle établit une communication bidirectionnelle en temps

réel entre le serveur et le navigateur par WebSocket, utilisée pour transmettre les commandes de

l'utilisateur (joystick, modes, DEL, séquences de blocs) et les mises à jour d'état du véhicule.

- Eventlet : bibliothèque de programmation réseau concurrente pour Python (Eventlet

Contributors, s.d.). Employée comme mode d'exécution asynchrone du serveur, elle gère en

parallèle, sans blocage mutuel, la capture vidéo, l'analyse de vision et les échanges WebSocket.

- OpenCV : bibliothèque de vision par ordinateur, développée à l'origine par Intel puis maintenue

par la fondation Open Source Vision (Open Source Vision Foundation, s.d.). Elle capture les

images de la caméra USB, les encode en JPEG pour le flux vidéo et effectue la détection visuelle

des feux de circulation et des lignes au sol.

Côté client :

- Socket.IO (bibliothèque cliente JavaScript) : pendant, côté navigateur, de Flask-SocketIO

(Socket.IO, s.d.). Elle envoie et reçoit les événements en temps réel, comme la position du

joystick ou les changements d'état, sans recharger la page.

- Blockly : bibliothèque de programmation visuelle par blocs, développée à l'origine par Google

(Google, s.d.-a) et en transition vers la Raspberry Pi Foundation depuis novembre 2025. Elle

constitue l'onglet de programmation, avec sept blocs personnalisés définis pour le projet et une

interface en français.

- Google Fonts (Open Sans, Roboto Mono) : polices web chargées depuis le service Google Fonts

pour l'habillage visuel de l'interface (Google, s.d.-b).

### 4.4.3 Architecture de l'application web

L'interface de contrôle repose sur un serveur Flask couplé à Flask-SocketIO, exécuté directement du

côté Linux (Qualcomm QRB2210) de l'Arduino UNO Q, sur le port 7000. Le serveur remplit trois rôles :

servir l'application web statique, diffuser le flux vidéo de la caméra en MJPEG et gérer la communication

en temps réel avec le navigateur par WebSocket.

Le serveur s'exécute en mode asynchrone au moyen d'eventlet, ce qui lui permet de gérer en parallèle,

sans blocage mutuel, la capture vidéo, l'analyse de vision et les échanges WebSocket avec le client.

Les commandes reçues ne pilotent pas directement le matériel. Elles passent par les modules embarqués

développés par le reste de l'équipe (comm_bridge, navigation, vision, boucle_vision), qui font le pont vers le contrôle des moteurs et des DEL en I2C ainsi que vers le traitement des images. Du point de vue de

l'interface web, ces modules constituent une boîte noire, dont le fonctionnement interne est documenté

dans les sections correspondantes du rapport. La figure 4.11 présente cette architecture.

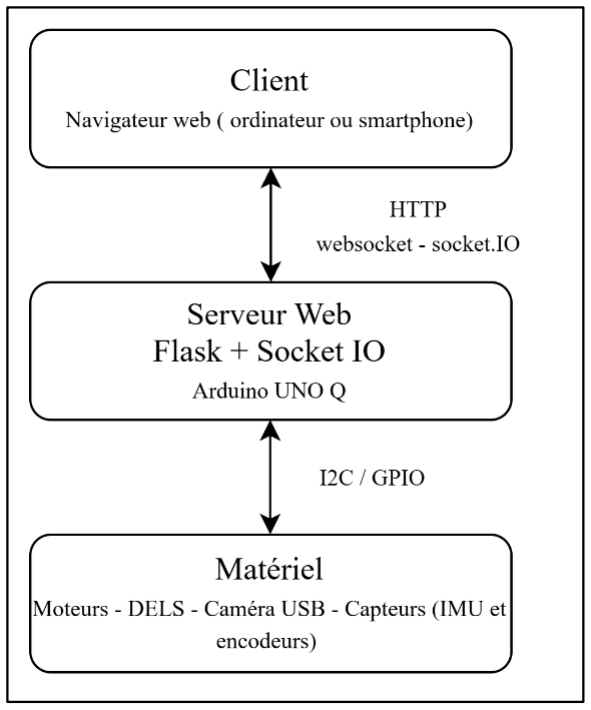
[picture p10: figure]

Figure 4.11 Architecture de l’interface web

### 4.5 Liste de matériel

Tableau 4.6 Liste du matériel utilisé pour la réalisation du prototype

Composante | Modèle | Quantité
Bouton Poussoir | PBS-LED-1624WH-L | 1
Câble QWIIC | STEMMA QT QWIIC JST SH CABLE 150 | 1
Câble QWIIC | JST SH 4-PIN CABLE - QWIIC COMPA | 1
Câble QWIIC | JST SH 4-PIN TO PREMIUM MALE HEA | 1
Câble USB-C | CAB-309PR | 1
Caméra | Logitech C270 | 1
Capteur ultrason | HC-SR04 | 1
Châssis | Hiwonder Full-Metal Tank Robot | 1
Concentrateur QWIIC | STEMMA QT 5 PORT PASSIVE HUB | 1
DC-DC Step down | PSM-305 DC-DC 7V-28V à 5V 3A | 1
Écran LCD | ARD-LCD-2.4 Écran LCD TFT 2,4” pour Arduino UNO / MEGA | 1
Fusible | GMA/3A Fusible 3A/ Action Rapide | 1
Gyroscope | 6 DOF SENSOR - MPU6050 | 1
LED | LED-STRIP-13-1M | 1
LIDAR | Capteur de Distance LIDAR 8m TF-Luna | 1
Microcontrôleur | ARDUINO UNO Q 2GB RAM 16GB EMMC | 1
Porte Fusible | FH501 | 1
Servo moteur | GK-SERVO-9G geeekus Servomoteur analogique 180 degrés 9G | 1
USB 2.0 Breakout Board | BB-USB Platine à déploiement USB 2.0 femelle | 1
Câble Dupont | Câbles de pontage | 1
Circuit imprimé | Carte de support Arduino UNO Q, conception EasyEDA Pro | 1
Coque | Impression 3D en PLA | S.O.

### 4.6 Plans de tests et validation

La validation suit trois niveaux : essais unitaires par sous-système, essais d'intégration entre sous-

systèmes, puis essais système sur le véhicule complet. Les essais unitaires s'exécutent sur banc et

caractérisent la précision des capteurs ainsi que la réponse des composantes avant toute intégration. Les

essais d'intégration valident ensuite les interfaces : circulation des données entre le microprocesseur et le

microcontrôleur, liaison sans fil, chaîne de vision et asservissement en boucle fermée. Chaque protocole

définit une procédure et un critère d'acceptation mesurable. Le tableau 4.6 regroupe ces deux niveaux.

Tableau 4.7 Protocoles d'essais unitaires et d'intégration

Niveau | Élément validé | Procédure | Critère d'acceptation
Unitaire | Capteur ultrasonique HC-SR04 | Mesures sur rail gradué à 10, 25, 50, 100, 200 et 300 cm | Écart ≤ 10 cm sur la plage
Unitaire | Lidar TF-Luna | Même protocole ; cibles réfléchissante et absorbante | Écart ≤ 10 cm ; matériaux hors spéc. identifiés
Unitaire | Gyroscope MPU-6050 | Rotations imposées de 45°, 90° et 180° sur plateau gradué | Erreur ≤ 5° ; dérive ≤ 2° après 60 s
Unitaire | Moteurs et encodeurs | Consignes PWM croissantes, roues libres | Réponse linéaire ; écart entre chenilles ≤ 1 %
Unitaire | Caméra Logitech C270 | Capture d'un flux sur mire de couleurs | 1280 × 720 à 30 fps ; latence ≤ 200 ms
Unitaire | Signaux lumineux et écran | Activation individuelle de chaque DEL et zone d'affichage | Réponse conforme des 5 signaux et de l'écran
Intégration | Communication MPU–MCU | Transmission de consignes de mode, 10 trames consécutives | Délai ≤ 50 ms ; aucune perte de trame
Intégration | Liaison Wi-Fi et application web | Essais à 5, 10, 15 et 20 m, dégagé puis avec cloison | Taux de réponse 100 % ; latence ≤ 100 ms à 20 m
Intégration | Chaîne de vision | Traitement OpenCV du flux sur tracé de référence | Cadence ≥ 10 img/s sans accumulation de retard
Intégration | boucle fermée Asservissement en | Consigne rectiligne sur 2 m | Déviation latérale ≤ 10 cm

Les essais système valident le véhicule complet dans ses conditions d'utilisation prévues. Chacun se

rattache directement à un objectif du projet, ce qui permet de positionner sur son atteinte au chapitre 5.

Tableau 4.8 Protocoles d'essais système

Essai | Objectif visé | Montage | Critère d'acceptation
mode manuel Pilotage en | Obj. 3 | Parcours libre depuis l'application web | Réponse fidèle ; aucune perte de liaison
entre modes Commutation | Obj. 3 | Véhicule en marche, commutation depuis l'interface | Prise d'effet ≤ 10 s
Portée de la liaison | Obj. 3 | Distances croissantes jusqu'à 20 m | Taux de réponse 100 % à 20 m
trajectoire Suivi de | Obj. 4 | Parcours balisé de 4 m, quatre virages | Écart latéral ≤ 10 cm sur tout le tracé
obstacle Arrêt sur | Obj. 4 | Approche frontale à vitesse constante | Arrêt complet ≤ 10 cm de l'obstacle
d'obstacle Contournement | Obj. 4 | Obstacle unique sur trajectoire rectiligne | Aucun contact ; retour sur la trajectoire initiale
feux Détection des | N/A | Feu maquette à distance variable | Couleur correctement identifiée ; portée max. relevée
Signaux lumineux programmables | Obj. 2 | Séquences composées en mode blocs | Exécution conforme des cinq signaux
énergétique Autonomie | N/A | Fonctionnement continu en mode manuel | Durée ≥ 30 min sur une charge
l'interface Utilisabilité de | Obj. 5 | Essai par tâches, 3 étudiants sans formation | Toutes les tâches réussies en < 5 min

L'objectif 5 exige une validation par des utilisateurs réels plutôt que par l'équipe de conception. Le

protocole retenu confie à chaque participant une série de tâches concrètes, sans explication ni assistance :

connexion au réseau du véhicule, pilotage manuel, activation d'un signal lumineux désigné, commutation

vers le mode blocs et composition d'une séquence. L'observateur consigne la réussite et le temps requis.

Cette méthode substitue une mesure de performance à une appréciation subjective.

L'ensemble des essais se déroule en laboratoire, sur surface uniforme et sous éclairage stable. Cette

maîtrise garantit la reproductibilité des mesures, mais restreint la portée des résultats pour le sous-système

de vision, sensible à l'éclairage ambiant. La section 5.2 discute cette limite.

CHAPITRE 5

ANALYSE DES RÉSULTATS

Ce chapitre confronte les résultats des essais aux six objectifs de la section 1.3. Chaque objectif reprend

son critère d'acceptation, sa valeur mesurée et son verdict. Les mesures proviennent du banc d'essai décrit

à la section 4.6. Les essais fonctionnels correspondent aux tâches 3.19 à 3.21 du diagramme de Gantt

(ANNEXE XI).

### 5.1 Résultats obtenus par rapport aux objectifs

Le tableau 5.1 présente la synthèse des résultats mesurés. Les sous-sections qui suivent détaillent les

conditions d'essai et les observations propres à chaque objectif.

Tableau 5.1 Synthèse des résultats obtenus par rapport aux objectifs du projet

# | Objectif | Critère visé | Résultat mesuré | Atteint

1 | Concevoir un véhicule électrique téléguidé fonctionnel dans les limites du budget et du délai de projet | ≤ 500 $ CAD ; remise avant la date limite | 486,20 $ CAD ; tous les livrables remis dans les délais | Oui
2 | Intégrer au moins quatre signaux lumineux fonctionnels programmables par les élèves | ≥ 4 signaux programmables | 4 dispositifs, 5 comportements commandables | Oui
3 | Implémenter trois modes de contrôle distincts : manuel, programmé et autonome | Commutation < 10 s ; fiabilité de réponse 100 % dans un rayon de 20 m | Trois modes pleinement fonctionnels ; commutation instantanée ; 100 % au-delà de 50 m | Oui
4 | Implémenter un système de navigation intelligent | Écart de trajectoire ≤ 10 cm ; arrêt complet ≤ 10 cm d'un obstacle | Écart < 10 cm sur 4 m et quatre virages ; arrêt à 5 cm ; contournement sans contact | Oui
5 | Offrir une interface de contrôle intuitive compréhensible en moins de 5 minutes sans formation préalable | < 5 min sans formation préalable | 2 min (n = 3 étudiants), toutes les tâches réussies | Oui
6 | Démontrer une méthodologie d'ingénierie rigoureuse incluant la traçabilité et le respect des jalons | Traçabilité documentée ; jalons respectés | Matrices de décision (ANNEXES VI-X), Git, GitHub Projects ; 4 jalons sur 4 respectés | Oui

### 5.1.1 Objectif 1 - Véhicule fonctionnel dans les limites de budget et de délai

Le coût total des composantes acquises s'élève à 486,20 $ CAD, soit 97 % du budget alloué.

L'ANNEXE V détaille la ventilation des dépenses. L'équipe emprunte par ailleurs une partie du matériel de prototypage à l'ÉTS. Cette pratique réduit le déboursement sans compromettre la reproductibilité, des

fournisseurs établis commercialisant l'ensemble des composantes du véhicule final. Le projet respecte

donc la contrainte budgétaire.

L'objectif fixe la remise de tous les livrables avant la date de la présentation orale. L'équipe complète

le prototype, la documentation technique et les livrables académiques dans ce délai. Le projet satisfait

donc également la contrainte temporelle.

### 5.1.2 Objectif 2 - Signaux lumineux programmables

Le véhicule intègre quatre dispositifs lumineux distincts pilotés par le microcontrôleur : un gyrophare

avant, un gyrophare arrière, un clignotant gauche et un clignotant droit. Les feux de freinage réutilisent

les DEL des clignotants arrière, ce qui porte à cinq le nombre de comportements lumineux commandables.

L'application web donne accès à l'ensemble de ces signaux, en commande directe comme en

programmation par blocs. Le prototype respecte donc le critère de quatre signaux programmables.

### 5.1.3 Objectif 3 - Trois modes de contrôle distincts

L'équipe implémente les trois modes de contrôle prévus. Les modes manuel, programmé et autonome

fonctionnent pleinement. Des essais répétés confirment leur fiabilité. Les essais valident de plus la

coexistence du mode programmé et du suivi de ligne, les deux fonctions s'exécutant sans conflit de

consigne.

L'application web déclenche la commutation entre les modes. Le véhicule répond dès la sélection, sans

délai perceptible. L'architecture retenue explique cette performance : la sélection transmet un simple

changement d'état au microcontrôleur temps réel, sans réinitialisation ni rechargement de programme. Le

système respecte donc largement le critère de dix secondes.

L'Arduino UNO Q héberge directement le réseau Wi-Fi. Le téléphone de l'utilisateur s'y connecte pour

accéder à l'application web. Cette topologie supprime toute dépendance à une infrastructure réseau

externe, avantage déterminant en démonstration scolaire. Les essais de portée se déroulent en espace

intérieur complètement dégagé. Le véhicule répond à l'ensemble des commandes au-delà de 50 m, soit

plus du double du rayon exigé. La latence demeure imperceptible sur cette plage. Elle atteint toutefois 3 s à 70 m, distance au-delà de laquelle le pilotage perd toute fluidité. Le prototype dépasse donc largement

le critère de fiabilité à 20 m.

### 5.1.4 Objectif 4 - Système de navigation intelligent

Pour le suivi de trajectoire, le parcours d'essai mesure environ 4 m et comporte quatre virages. L'écart

latéral demeure inférieur à 10 cm sur l'ensemble du tracé. Les sorties de virage, où l'écart culmine

structurellement, respectent également ce seuil. Le prototype atteint donc le critère de précision de

trajectoire.

Pour l’évitement d’obstacles, la fusion des données du HC-SR04 et du lidar TF-Luna détecte l'obstacle.

Le véhicule stoppe à 5 cm en moyenne, pour une vitesse d'approche inférieure à 1 m/s. Il contourne ensuite

l'obstacle par la droite ou par la gauche, sans contact, puis reprend le suivi de ligne. Le prototype atteint

donc le critère d'arrêt à 10 cm, avec une marge de 50 %.

La rotation finale vers la ligne est plus ouverte que celle d'écartement, pour une raison qui n'a rien de géométrique. À 45°, la ligne sort du champ de la caméra avant d'être recroisée, et le suivi s'arrête sans

jamais la retrouver. Un angle de 20° la garde en vue, au prix d'une approche plus longue, soit environ 93

cm parcourus contre 45 cm. Le véhicule abandonne par ailleurs la manœuvre après trois tentatives

infructueuses et demeure immobilisé, comportement volontaire devant un obstacle infranchissable.

Pour la détection des feux de circulation, le véhicule détecte le feu à environ 50 cm et s'immobilise au

rouge. Il repart au vert sans intervention. Les essais confirment ce comportement en marche. Le sous-

système de vision discrimine correctement la couleur jusqu'à cette distance. Au-delà, l'algorithme perd sa

capacité de différenciation chromatique fiable. La section 5.2 analyse cette limite.

### 5.1.5 Objectif 5 - Interface de contrôle intuitive

L'équipe valide l'interface auprès de trois étudiants sans formation préalable. La méthode retenue

repose sur un essai d'utilisabilité par tâches. Chaque participant accomplit une série de tâches concrètes

sans assistance. L'observateur consigne la réussite ou l'échec de chacune ainsi que le temps requis. Cette

approche écarte toute appréciation subjective au profit d'une mesure de performance.

Les tâches couvrent la connexion au réseau du véhicule et l'accès à l'application web. S'y ajoutent le

pilotage en mode manuel et l'activation d'un signal lumineux précis, le gyrophare par exemple. Les

participants commutent enfin vers le mode blocs et composent une séquence de déplacement.

Les trois participants réussissent l'ensemble des tâches en deux minutes environ. Le prototype atteint

donc le critère de cinq minutes, avec une marge de 60 %. Ce résultat valide le choix de la programmation

par blocs plutôt qu'une interface textuelle, la composition de séquences ne nécessitant aucune explication

préalable. L'échantillon de trois participants limite toutefois la portée statistique du résultat. La section 5.2

discute cette limite.

### 5.1.6 Objectif 6 - Méthodologie d'ingénierie rigoureuse

La traçabilité des décisions techniques repose sur trois niveaux. Les matrices de décision des

ANNEXES VI à X documentent les choix de composantes. Chacune explicite les critères, la pondération

et le barème menant à la sélection retenue. Git conserve l'historique complet du développement logiciel,

le travail progressant sur des branches dédiées fusionnées après revue par un second membre. Un tableau

Kanban sous GitHub Projects suit enfin l'avancement des tâches.

Le diagramme de Gantt de l'ANNEXE XI formalise la planification. Il identifie pour chaque tâche un

responsable, des dates, une durée et un effort estimé. Il signale également l'appartenance de chaque tâche

au chemin critique. L'équipe respecte les quatre jalons du projet, soit le rapport de proposition, le rapport

d'étape, le rapport technique final et la présentation orale. Les tâches du chemin critique font l'objet d'un

suivi rapproché, notamment le développement des modes manuel et autonome ainsi que l'interface

utilisateur. Le projet atteint donc l'objectif de rigueur méthodologique.

### 5.2 Analyse des écarts et déviations

Le prototype atteint l'ensemble des six objectifs. Aucun écart de performance ne subsiste. Quatre

limites encadrent toutefois la portée des résultats. Cette section en expose les causes techniques et en

évalue l'incidence pour le client.

### 5.2.1 Limite de portée de la détection des feux de circulation

La détection des feux devient inconstante au-delà de 50 cm environ. Le feu est encore reconnu par

intermittence à plus grande distance, mais sans la régularité qu'exige une navigation anticipative. Plusieurs

mécanismes concourent à cette dégradation. La surface du feu projetée sur le capteur diminue

quadratiquement avec la distance, et le nombre de pixels disponibles chute sous le seuil d'une

discrimination chromatique robuste. La littérature confirme ce mécanisme : le feu occupe peu de pixels et

présente une structure de caractéristiques éparse, ce qui dégrade la reconnaissance (Wang et al., 2021).

Yoneda et al. (2020) situent l'effondrement du taux de reconnaissance sous la barre des dix pixels. La source lumineuse sature de surcroît les pixels centraux. Ce débordement efface le détail chromatique et

déforme la teinte mesurée (Zivid, s.d.). L'équipe n'a pas isolé la contribution respective de ces mécanismes.

Une mesure séparant le taux de détection du taux de classification correcte de la couleur permettrait

d’identifier la cause.

Cette fonctionnalité ne figure pas parmi les six objectifs formels du projet. Elle enrichit le mode

autonome sans conditionner son acceptation. La portée obtenue convient à l'usage pédagogique visé, les

parcours de démonstration se concevant à l'échelle d'une salle de classe. Le chapitre 7 reprend deux pistes

d'amélioration : un objectif à focale plus longue, ou une détection fondée sur la position relative des feux.

### 5.2.2 Absence de délai de garde sur la liaison sans fil

Le pilotage manuel ne comporte aucun délai de garde. Le microcontrôleur conserve la dernière

consigne reçue en l'absence de nouvelle trame. Le client émet bien une consigne nulle au relâchement du

joystick. Une coupure brutale de la liaison contourne toutefois ce mécanisme, le véhicule maintenant alors

sa dernière vitesse.

L'équipe n'a pas soumis ce scénario à un essai formel. Le comportement découle de la lecture du code,

documentée à la section 4.3. La portée mesurée au-delà de 50 m rend une coupure improbable dans une

salle de classe. Le risque demeure néanmoins réel en cas de défaillance du point d'accès. Le chapitre 7

recommande l'ajout d'un délai de garde arrêtant les moteurs après quelques centaines de millisecondes

sans commande.

### 5.2.3 Limites de la validation

Deux limites affectent la portée des résultats présentés. L'échantillon de trois participants fournit une

indication qualitative de l'utilisabilité. Il ne soutient aucune conclusion statistiquement représentative de

la population cible. Une validation auprès d'une classe complète consoliderait ce résultat.

Les essais de navigation se déroulent en laboratoire contrôlé. La surface demeure uniforme et l'éclairage

stable. Le sous-système de vision réagit fortement aux conditions d'éclairage ambiant. Les performances

de suivi de ligne et de détection pourraient donc varier en contexte réel. Le chapitre 7 reprend ces deux

limites sous forme de recommandations.

### 5.2.4 Limite de couverture du lidar

Le TF-Luna n'éclaire qu'un faisceau de 2°. Le balayage par servomoteur élargit cette couverture à trois

secteurs, mais il immobilise le véhicule pendant environ une seconde à chaque obstacle. Le barème de

l'ANNEXE VII avait accordé à ce capteur la cote d'un relevé à 360°, ce que le montage ne réalise pas.

Le capteur conserve néanmoins sa place dans la solution. Sa précision de ±6 cm et sa lecture directe en

I2C répondent au besoin réel, qui est de mesurer une distance frontale et de choisir un côté de

contournement, non de relever une carte de l'environnement. L'arrêt d'une seconde demeure sans

conséquence pour l'usage pédagogique visé, où le véhicule évolue à faible vitesse devant un public. Un

lidar rotatif lèverait cette limite en fournissant un relevé continu. Son coût et son intégration logicielle

dépassaient toutefois le budget et le calendrier du projet. Le chapitre 7 reprend cette avenue.

CHAPITRE 6

IMPACTS ENVIRONNEMENTAUX ET BIEN-ÊTRE

Le véhicule téléguidé autonome entraîne des répercussions qui dépassent sa seule fonction technique.

Cette section analyse ces répercussions dans une optique de développement durable en suivant le produit

de sa fabrication jusqu'à sa fin de vie, puis en s’attaquant aux effets sur la santé et la sécurité des personnes

qui l'utiliseront.

### 6.1 Cycle de vie du produit

La fabrication du véhicule mobilise trois grandes familles de matériaux, chacune ayant son empreinte

écologique. D'abord, les composants électroniques, l'Arduino UNO Q, les capteurs, l'écran, les DEL et le

câblage, reposent sur des métaux et des terres rares dont l'extraction et le raffinage sont énergivores et

générateurs de déchets. Ensuite, la batterie lithium-ion intégrée au châssis Hiwonder recueille l'essentiel

de l'enjeu environnemental à la fabrication soit leur extraction du lithium et du cobalt. Il est reconnu pour

sa consommation d'eau et ses impacts sur les milieux miniers. Enfin, la coque et les supports imprimés en

3D sont en PLA, un plastique d'origine végétale, mais les retailles, les supports d'impression et les pièces

ratées constituent une source de déchets non négligeable.

L'équipe a toutefois fait des choix qui atténuent cette empreinte dès la conception. Le recours à des composantes empruntées à l'École et aux membres de l'équipe a permis de réutiliser du matériel déjà en

circulation plutôt que d'acheter du neuf. La sélection d'un châssis tout-en-un déjà équipé d'une batterie

rechargeable évite aussi le recours à des piles jetables. L'exigence de reproductibilité pousse aussi vers

des composantes standard et disponibles chez des fournisseurs établis, ce qui allonge leur durée de vie

utile et facilite le remplacement d'une pièce unique sans jeter l'ensemble.

Le transport des composantes pèse également sur le bilan, mais l'approvisionnement en limite la portée.

Le châssis provient d'un fournisseur asiatique, ce qui allonge la chaîne pour la pièce la plus lourde du

véhicule. Les autres composantes ont été achetées chez un distributeur local ou fournies par le département de génie électrique de l'ÉTS. Cette proximité réduit la distance parcourue par la majorité du matériel et

raccourcit du même coup le délai de remplacement d'une pièce défectueuse.
À l'usage, l'empreinte du véhicule est faible. Il fonctionne sur batterie rechargeable, sans émission

directe, et sa consommation se limite à quelques recharges lors des démonstrations. La conception modulaire, en paires de fichiers et en sous-systèmes isolables, prolonge cette phase d'utilisation. Une

équipe future peut réparer ou faire évoluer un module précis plutôt que de repartir de zéro.

La fin de vie demeure l'étape la plus délicate. La batterie lithium-ion exige une filière de récupération

spécialisée et ne doit jamais aboutir aux ordures ménagères. Les cartes électroniques relèvent quant à elles

de la filière des déchets électroniques, qui permet de récupérer une partie des métaux. Le PLA, bien que

biosourcé, ne se composte pas dans les conditions domestiques et se traite le plus souvent comme un

déchet ordinaire. Sa vertu principale reste d'être imprimé en quantités raisonnables. Dans l'ensemble, la

nature modulaire et réparable du véhicule est ce qui repousse le plus efficacement cette fin de vie soit en

gardant les composantes en service le plus longtemps possible.

### 6.2 Impacts sur la santé et la sécurité

Le véhicule téléguidé autonome est destiné à être manipulé par des élèves du secondaire et du cégep

lors de démonstrations. La sécurité des utilisateurs a ainsi été traitée comme une contrainte de conception

à part entière plutôt que comme une considération secondaire. Un véhicule chenillé motorisé qui circule

parmi des spectateurs présente un risque réel de collision et de blessures légères. Alors, deux mesures

concrètes ont été prévues pour l'encadrer.

D'abord, l'aire de démonstration est délimitée par des bordures physiques qui maintiennent le véhicule

à distance des spectateurs et contiennent sa trajectoire. Ensuite, la vitesse maximale est plafonnée par

logiciel, de sorte qu'un débordement de trajectoire ou une erreur de commande ne se traduise jamais par

un impact à trop haute vitesse.

Le projet comporte une dimension de bien-être plus positive. En rendant tangibles les principes de

l'ingénierie et en exposant ouvertement l'architecture et les algorithmes du véhicule, le véhicule téléguidé

autonome cherche à raviver l'intérêt des jeunes pour les carrières techniques, dans un contexte où le

décrochage scolaire et la pénurie de main-d'œuvre qualifiée pèsent sur la société québécoise. Cet effet

éducatif, bien que difficile à quantifier, constitue la contribution sociale la plus significative du projet.

CHAPITRE 7

CONCLUSION ET RECOMMANDATIONS

### 7.1 Rappel du projet et des objectifs

Le projet vise à concevoir et prototyper un véhicule téléguidé capable de téléopération, de perception

de son environnement, de détection d'obstacles et de navigation autonome. Une intention pédagogique le

sous-tend : bâtir un outil concret illustrant le processus d'ingénierie devant des jeunes du secondaire et du

cégep. Le défi réside dans cet équilibre. La plateforme doit fonctionner réellement au terme d'une seule

session, sans sacrifier la clarté ni la modularité permettant à la prochaine équipe de reprendre le projet à

l'automne 2026.

L'équipe vise concrètement quatre fonctionnalités : piloter le véhicule à distance avec retour vidéo en

direct, détecter et éviter les obstacles, suivre une ligne au sol de façon autonome et offrir une interface de

programmation par blocs pour enchaîner des déplacements précis. Ces besoins fonctionnels dictent les

choix techniques. Le cœur du système repose sur l'Arduino UNO Q, qui marie un processeur applicatif

QRB2210 sous Debian et un microcontrôleur temps réel STM32U585. Le logiciel reprend cette séparation

: un micrologiciel C++ assure le contrôle moteur en temps réel, tandis qu'un serveur Python sous Flask et

WebSocket gère la vision par OpenCV et YOLOv8n.

### 7.2 Fonctionnement du prototype et résultats obtenus

Le prototype atteint les six objectifs du projet. Le coût total des composantes s'élève à 486,20 $ CAD,

sous le plafond de 500 $CAD. L'équipe remet l'ensemble des livrables avant la date de présentation.

Les trois modes de contrôle fonctionnent pleinement. Le pilotage manuel répond à l'ensemble des

commandes au-delà de 50 m en espace dégagé, soit plus du double du rayon exigé. La commutation entre

modes s'effectue sans délai perceptible. Le mode programmé exécute des séquences de blocs combinant

déplacements, rotations et signaux lumineux, sans conflit avec le suivi de ligne.

La navigation autonome respecte les deux critères de précision. Le véhicule suit une ligne au sol avec

un écart latéral inférieur à 10 cm sur un parcours de 4 m comportant quatre virages. Il s’arrête à 5 cm d'un obstacle, le contourne sans contact, puis reprend le suivi. Il détecte de plus les feux de circulation à 50 cm,

s'immobilise au rouge et repart au vert.

L'interface valide son objectif d'accessibilité. Trois étudiants sans formation préalable accomplissent l'ensemble des tâches assignées en deux minutes. L'autonomie énergétique dépasse enfin largement la durée d'une démonstration en salle de classe.

Le prototype répond donc au besoin du promoteur : un véhicule familier, modifié pour illustrer

concrètement le travail d'ingénierie devant un public scolaire.

### 7.3 Leçons apprises

L'approvisionnement conditionne l'échéancier. L'acquisition des composantes occupe trois

semaines du chemin critique. Ce délai repousse l'intégration matérielle et comprime la fenêtre de validation en fin de projet. Les restrictions d'achat en vigueur à l'ÉTS écartent les fournisseurs à livraison

rapide. Une équipe future gagnerait à lancer les commandes dès la première semaine, avant même la

finalisation du concept.

La nouveauté technologique impose un coût d'apprentissage. L'Arduino UNO Q paraît quelques

mois avant la session. Sa documentation demeure alors partielle, en particulier sur le pont RPC entre le

microprocesseur et le microcontrôleur. Cette incertitude justifie rétrospectivement le choix d'une méthode

itérative. Elle rappelle qu'une composante récente échange des capacités supérieures contre un risque

d'intégration accru.

La mesure prime sur l'intuition. Le patinage des chenilles fausse toute estimation odométrique en

rotation. L'équipe substitue l'intégration gyroscopique aux encodeurs après constat expérimental. De

même, la manœuvre de contournement ne ramène le véhicule sur la ligne qu'avec un angle de retour plus

faible que l'angle d'écartement. La géométrie seule commandait l'inverse, soit un retour au moins aussi

franc que l'aller. C'est le champ de la caméra qui impose l'angle retenu, la ligne sortant du cadre avant

d'être recroisée sur une approche trop directe. L'ajustement vient de l'essai, non du calcul.

La simplicité suffit souvent. Les mouvements programmés reposent sur un contrôleur à seuil plutôt

que sur un correcteur PID. Ce choix évite le réglage de gains, hors du budget temporel disponible. Il

satisfait néanmoins les critères de précision aux vitesses retenues.

### 7.4 Recommandations et perspectives

Trois améliorations à court terme précèdent les évolutions structurantes. Une caméra grand angle

élargirait le champ de vision et corrigerait la principale faiblesse observée : la ligne sort fréquemment du

cadre en virage serré, ce qui interrompt le suivi. Un délai de garde sur la liaison sans fil arrêterait les

moteurs après quelques centaines de millisecondes sans commande, écartant tout emballement en cas de

coupure. Une carrosserie conçue en collaboration avec des étudiants en génie de la conception renforcerait

enfin l'attrait visuel du véhicule, facteur déterminant pour l'objectif pédagogique.

Plusieurs pistes structurantes se dégagent ensuite de l'état actuel de la plateforme. L'ajout d'un

algorithme de cartographie et de localisation simultanées constitue l'évolution la plus logique, la

plateforme disposant déjà des capteurs nécessaires pour amorcer une localisation relative. Un jumeau

numérique, reproduisant le véhicule dans un simulateur comme Gazebo ou Unity, permettrait de tester de

nouveaux algorithmes de navigation sans risquer le matériel, ce qui accélérerait les itérations futures. Sur

le plan des communications, un protocole véhicule-à-véhicule ouvrirait la voie aux déplacements en

formation et à un évitement coopératif entre plusieurs unités.

La robustesse du système appelle enfin deux chantiers. La carte de circuit imprimé conçue durant le

projet ne reçoit aujourd'hui que l'Arduino UNO Q. Son extension aux connecteurs des périphériques

supprimerait le câblage de prototypage, qui demeure le point le plus fragile du montage. Chaque capteur,

chaque bandeau lumineux et l'écran y disposeraient d'une empreinte dédiée, ce qui fiabiliserait les

connexions et faciliterait la reproduction. L'évolution de l'application web vers une application native iOS

et Android offrirait une télémétrie en direct et une expérience utilisateur supérieure. L'ajout de capteurs

plus avancés, caméra de profondeur ou lidar 360°, assurerait par ailleurs une navigation fiable sous

éclairage variable, enjeu resté hors de portée dans le cadre de la présente session.

### 7.5 Pistes d'activités pédagogiques

Le promoteur destine la plateforme aux démonstrations en milieu scolaire. Les activités suivantes

exploitent le prototype comme support de projet étudiant. Elles se déclinent selon le niveau scolaire visé.

Niveau secondaire. Les élèves conçoivent leur propre parcours au sol, puis observent l'effet du

contraste et de la courbure sur la qualité du suivi. Ils programment ensuite une séquence de blocs

franchissant ce parcours en un minimum de temps, ce qui introduit la notion d'algorithme sans écriture de code. Ils composent des séquences lumineuses reproduisant la signalisation routière réelle. Ils modélisent

enfin une carrosserie et l'impriment en trois dimensions, activité couvrant le cycle complet de conception

d'une pièce.

Niveau collégial. Les étudiants conçoivent une manette dédiée sur circuit imprimé : capture du schéma,

routage, soudure et micrologiciel de communication. Ce projet couvre l'ensemble de la chaîne de

conception électronique. Ils intègrent également un capteur supplémentaire à la fusion existante, ce qui

exige la lecture d'une fiche technique et la maîtrise d'un protocole de communication. Ils entraînent un

modèle de vision sur de nouveaux panneaux de signalisation. Ils implémentent enfin un correcteur

proportionnel-intégral-dérivé, puis comparent ses performances au contrôleur à seuil actuel, exercice

illustrant concrètement l'apport de l'asservissement.

L'architecture modulaire du prototype rend chacune de ces activités indépendantes des autres. Un

groupe modifie un sous-système sans perturber le reste du véhicule.

ANNEXE I

DIAGRAMME FONCTIONNEL: VÉHICULE TÉLÉGUIDÉ

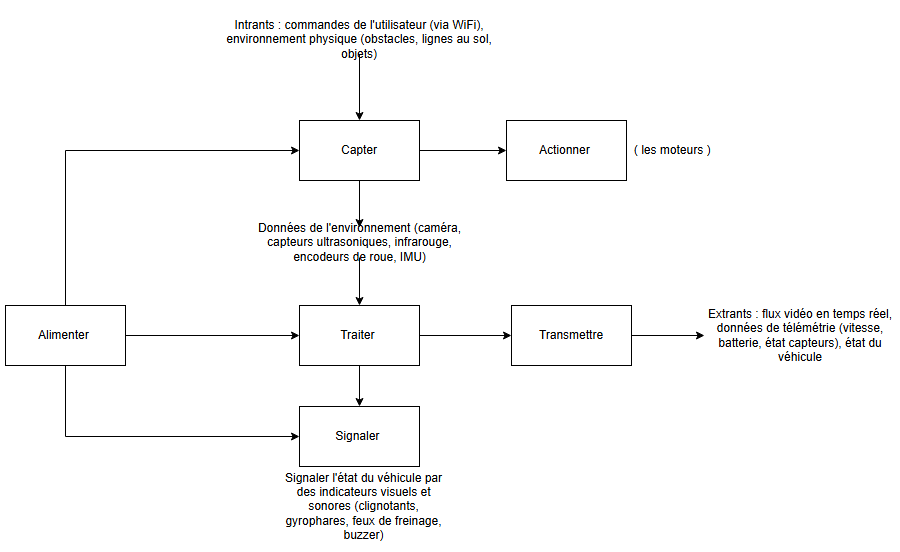
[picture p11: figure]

Figure-A I-1 Diagramme fonctionnel du véhicule téléguidé

ANNEXE II

DIAGRAMME FONCTIONNEL: INTERFACE UTILISATEUR

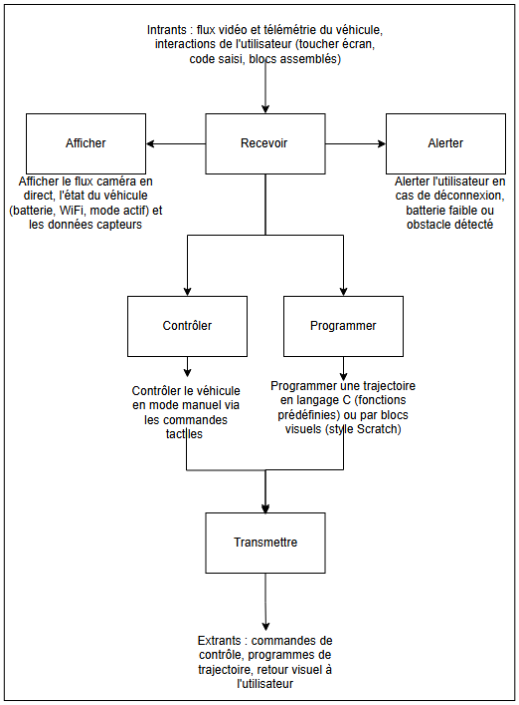
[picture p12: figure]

Figure-A II-1 Diagramme fonctionnel interface utilisateur

ANNEXE III

DIAGRAMME FONCTIONNEL: SYSTÈME DE NAVIGATION AUTONOME

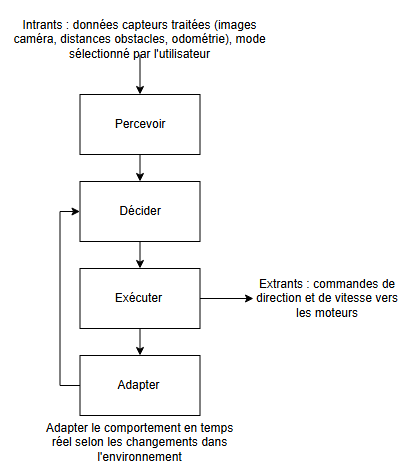
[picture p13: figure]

Figure-A III-1 Diagramme fonctionnel système de navigation

ANNEXE IV

REMUE-MÉNINGE DU SYSTÈME GLOBAL DU PROJET

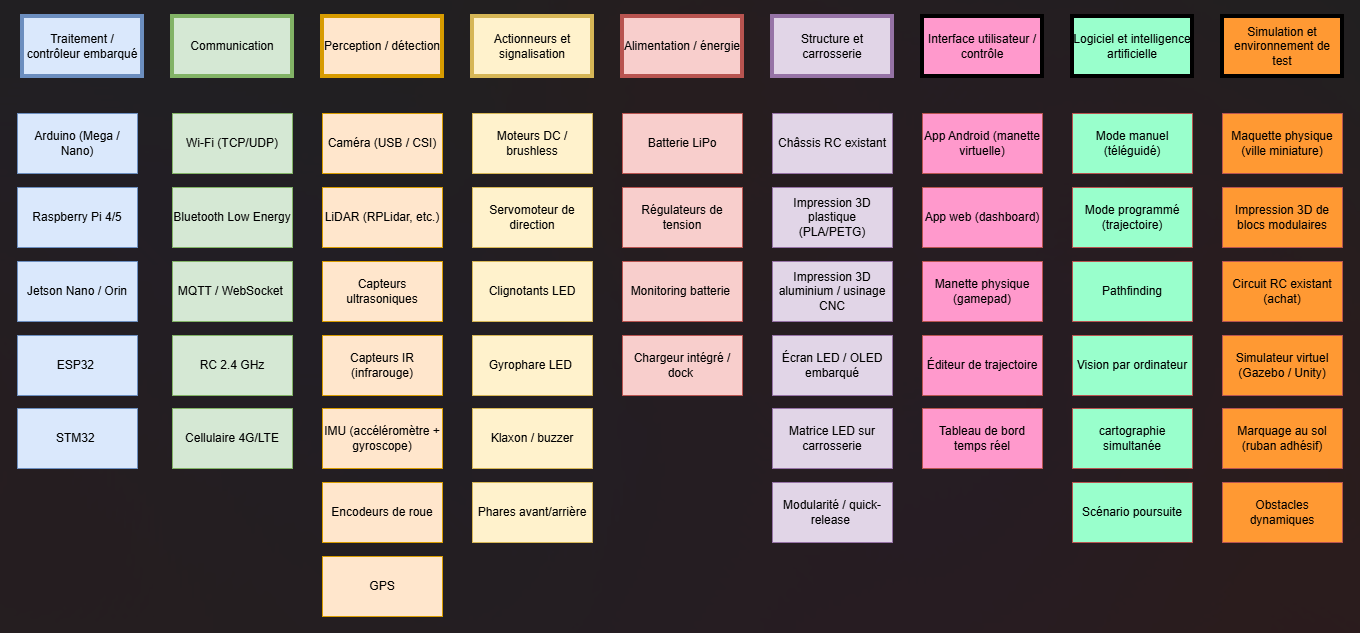
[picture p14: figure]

Figure-A IV-1 Remue-méninge du système global

ANNEXE V

ANALYSE FINANCIÈRE

Figure-A V-1 Analyse financière - Sous-système : Microcontrôleur

# | Composant / Description | Qté | Prix ($CAD) Sous-total ($CAD) | | Lien fournisseur

1 | Raspberry Pi 4 Model B (4 Go) | 1 | $139.95 | $139.95 | pishop
2 | Carte microSD 64 Go | 1 | $17.08 | $17.08 | walmart
| TOTAL DU CONCEPT | | | $157.03
# | Composant / Description | Qté | Prix ($CAD) Sous-total ($CAD) | | Lien fournisseur

1 | ESP32 DevKit (WiFi + BLE) | 1 | $15.40 | $15.40 | digikey
2 | Micro SD card reader | 1 | $2.75 | $2.75 | abra-electronics
3 | Carte microSD 64 Go | 1 | $16.58 | $16.58 | walmart
| TOTAL DU CONCEPT | | | $34.73
# | Composant / Description | Qté | Prix ($CAD) Sous-total ($CAD) | | Lien fournisseur

1 | ARDUINO UNO Q 4GB RAM 16GB EMMC | 1 | $85.24 | $85.24
| TOTAL DU CONCEPT | | | $85.24

digikey

Écart vs option la moins chère

Concept C : Arduino Uno Q (Architecture Hybride)

Récapitulatif comparatif
Concept
Raspberry Pi 4 (traitement haut niveau) | $122.30
ESP32 (contrôle temps réel) | -
Arduino Uno Q | $50.51

Analyse financière — Sous-système : Microcontrôleur

Concept A : Raspberry Pi 4 (traitement haut niveau)

Concept B : ESP32 (contrôle temps réel)

Figure-A V-2 Analyse financière - Sous-système : Communication sans fil

# | Composant / Description | Microcontrôleur | Norme | Qté | Prix ($CAD) | Sous-total ($CAD) | Lien fournisseur

1 | Module WiFi intégré | Rasberry Pi 2 GB | Wifi 5 (IEEE 802.11ac) | 1 | | - | Intégré — aucun achat
2 | | ESP 32 | Selon version | 1 | | - | Intégré — aucun achat
3 | | Arduino UNO Q | Wifi 5 (IEEE 802.11ac) | 1 | | - | Intégré — aucun achat
| TOTAL DU CONCEPT | | | | | -
# | Composant / Description | Microcontrôleur | Norme | Qté | Prix ($CAD) | Sous-total ($CAD) | Lien fournisseur

1 | Module BLE — intégré | Rasberry Pi 2 GB | BT 5 | 1 | | - | Intégré — aucun achat
2 | | ESP 32 | Selon version | 1 | | - | Intégré — aucun achat
3 | | Arduino UNO Q | BT 5.1 | 1 | | - | Intégré — aucun achat
| TOTAL DU CONCEPT | | | | | -
# | Composant / Description | Qté | Prix ($CAD) | Sous-total ($CAD) | Lien fournisseur

1 | Module nRF24L01 (SPI) | 1 | $7.68 | $7.68 | abra-electronics
| TOTAL DU CONCEPT | | | $7.68
# | Composant / Description | | | Qté | Prix ($CAD) | Sous-total ($CAD) | Lien fournisseur

1 | Module Xbee (USB) | | | 1 | $32.20 | $32.20 | robotshop
2 | Module Zigbee intégré | ESP32-C6/H2 | Zigbee (IEEE 802.15.4) | 1 | | - | Intégré — aucun achat
| TOTAL DU CONCEPT | | | | | $32.20

ZigBee

Bluetooth

RF 2,4 GHz

Récapitulatif comparatif (prix réels)

Concept

WiFi | - Écart vs option la moins chère

$7.68

$32.20

Concept C : RF 2,4 GHz via nRF24L01

Concept D : ZigBee (IEEE 802.15.4)

Analyse financière — Sous-système : Communication sans fil

Concept A : WiFi

Concept B : Bluetooth

Figure-A V-3 Analyse financière - Sous-système : Détection d’obstacles et navigation

# | Composant / Description | Qté | Prix ($CAD) | Prix ($CAD) | Lien fournisseur

1 | Capteur ultrason HC-SR04 | 1 | $2.88 | $2.88 | digikey
| TOTAL DU CONCEPT | | | $2.88
# | Composant / Description | Qté | Prix ($CAD) | Prix ($CAD) | Lien fournisseur

1 | Capteur IR Sharp GP2Y0A21YK (10-80cm) | 1 | $23.00 | $23.00 | Abra — Sharp GP2Y0A21YK
2 | Kitronik Line Following Board | 1 | $5.40 | $5.40 | robotshop
| TOTAL DU CONCEPT (MINIMUM) | | | $5.40
# | Composant / Description | Qté | Prix ($CAD) | Prix ($CAD) | Lien fournisseur

1 | Caméra Raspberry Pi v2 (8 MP) | 1 | $21.95 | $21.95 | pishop
| TOTAL DU CONCEPT | | | $21.95
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

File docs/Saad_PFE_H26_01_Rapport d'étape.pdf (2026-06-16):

ÉCOLE DE TECHNOLOGIE SUPÉRIEURE

UNIVERSITÉ DU QUÉBEC

RAPPORT TECHNIQUE
PRÉSENTÉ À L’ÉCOLE DE TECHNOLOGIE SUPÉRIEURE DANS LE CADRE DU PROJET DE FIN D’ÉTUDES DU BACCALAURÉAT EN GÉNIE ÉLECTRIQUE

RAPPORT D’ÉTAPE

PAR
Serby Brian, BARTHELEMY
Vlad Alexandru, ILIE
Yury, ERESHCHENKO
Ryan, LEUNG
Yoan, SAPET

MONTRÉAL, LE 12 JUIN 2026

I

## TABLE DES MATIÈRES

LISTE DES TABLEAUX | III
LISTE DES ABRÉVIATIONS, SIGLES ET ACRONYMES | IV
LISTE DES SYMBOLES ET UNITÉS DE MESURE | VI

CHAPITRE 5 ÉVALUATION DES CONCEPTS ET SÉLECTION DE LA SOLUTION FINALE ...... 7

II

ANNEXE I DIAGRAMME FONCTIONNEL: VÉHICULE TÉLÉGUIDÉ | 12
ANNEXE II DIAGRAMME FONCTIONNEL: INTERFACE UTILISATEUR | 13

ANNEXE III DIAGRAMME FONCTIONNEL: SYSTÈME DE NAVIGATION AUTONOME ........ 14

ANNEXE IV REMUE-MÉNINGE DU SYSTÈME GLOBAL DU PROJET | 15
ANNEXE V ANALYSE FINANCIÈRE | 16
ANNEXE VI MATRICES DE DÉCISION ET BARÈME DES MICROCONTRÔLEURS | 22
ANNEXE VII MATRICES DE DÉCISION ET BARÈME POUR LES DÉTECTIONS | 24
ANNEXE VIII MATRICES DE DÉCISION ET BARÈME POUR LA VISION | 26
ANNEXE IX MATRICES DE DÉCISION ET BARÈME POUR LA COMMUNICATION | 28
ANNEXE X MATRICES DE DÉCISION ET BARÈME POUR LE CHÂSSIS | 30
ANNEXE XI DIAGRAMME DE GANTT | 32
LISTE DE RÉFÉRENCES BIBLIOGRAPHIQUES | 34

III

LISTE DES TABLEAUX

IV

LISTE DES ABRÉVIATIONS, SIGLES ET ACRONYMES
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

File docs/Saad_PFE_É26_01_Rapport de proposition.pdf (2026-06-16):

ÉCOLE DE TECHNOLOGIE SUPÉRIEURE UNIVERSITÉ DU QUÉBEC

RAPPORT DE PROPOSITION PRÉSENTÉ À DOMINIK DÉSILETS ET SAAD MAAROUF DANS LE CADRE DU COURS ELE795 - PROJET DE FIN D’ÉTUDES EN GÉNIE ÉLECTRIQUE
GROUPE 1

PAR

BARTHELEMY, Serby Brian
ERESHCHENKO, Yury
ILIE, Vlad Alexandru
LEUNG, Ryan
SAPET, Yoan

MONTRÉAL, LE 19 MAI 2026

II

TABLE DES MATIÈRES

Page

### 1 Mise en contexte du projet

### 1.1 Problématique et justification sociale

Le Québec subit actuellement une rareté de main-d’œuvre technique qualifiée. En effet,

l’Ordre des ingénieurs prévoit plus de 50 000 postes vacants d’ici 2030 (OIQ, 2021). Le taux

de sorties sans diplôme ni qualification au secondaire s'élève à 14 % (ISQ, 2026). Cette

raréfaction d’experts techniques compromet la capacité d'innovation et la pérennité des
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

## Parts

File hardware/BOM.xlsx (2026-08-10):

Liste de matériel
Composante | Modèle | Fonction | QTY | Coût | Coût total | Lien | Provenance | Commentaire
Bouton Poussoir | PBS-LED-1624WH-L | Allumer | 1 | 4.95 | 5.69 | abra-electronics (https://abra-electronics.com/electromechanical/switches/pushbutton-switches-led/latching/pbs-led-1624wh-l.html) | Acheté
Câble QWIIC | STEMMA QT QWIIC JST SH CABLE 150 | Transmission | 1 | 1.41 | 1.62 | digikey (https://www.digikey.ca/fr/products/detail/adafruit-industries-llc/4397/10824270) | Acheté
Câble QWIIC | JST SH 4-PIN CABLE - QWIIC COMPA | Transmission | 1 | 1.41 | 1.62 | digikey (https://www.digikey.ca/fr/products/detail/adafruit-industries-llc/4210/10230021) | Acheté
Câble QWIIC | JST SH 4-PIN TO PREMIUM MALE HEA | Transmission | 1 | 1.41 | 1.62 | digikey (https://www.digikey.ca/fr/products/detail/adafruit-industries-llc/4209/10230003) | Acheté
Câble USB-C | CAB-309PR | Transmission | 1 | 2.95 | 3.39 | abra-electronics (https://abra-electronics.com/wire-cable-accessories/wirecable/usb-adapters-cables-hubs-other-en/usb-to-multi-types/right-angle-male-usb-type-c-4-wire-cable.html) | Acheté
Caméra | Logitech C270 | Vision | 1 | 40.58 | 46.67 | walmart (https://www.walmart.ca/en/ip/Logitech-C270-HD-Webcam-with-noise-reducing-mics-for-video-calls/6000196155058) | Acheté
Capteur ultason | HC-SR04 | Détection | 1 | 2.9 | 3.33 | digikey (https://www.digikey.ca/en/products/detail/olimex-ltd/SNS-HCSR04/21662590) | Membre de l'équipe
Chassis | Hiwonder Full-Metal Tank Robot | Mobilité | 1 |  | 186.71 | hiwonder (https://www.hiwonder.com/products/suspended-shock-absorbing-tracked-chassis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) | Acheté | Vient avec les moteurs encodeurs, la carte de contrôle, la batterie et le chargeur
Concentrateur QWIIC | STEMMA QT 5 PORT PASSIVE HUB | Transmission | 1 | 3.75 | 4.31 | digikey (https://www.digikey.ca/fr/products/detail/adafruit-industries-llc/5625/16819801) | Acheté
DC-DC Step down | PSM-305 DC-DC 7V-28V à 5V 3A | Alimenter | 1 | 4.6 | 5.29 | abra-electronics (https://abra-electronics.com/voltage-regulator-modules/dc-dc-step-down-converters/psm-305-dc-dc-7v-28v-to-5v-3a-fixed-step-down-converter-module.html) | Acheté
Écran LCD | ARD-LCD-2.4 Ecran LCD TFT 2,4” pour Arduino UNO / MEGA | Afficher | 1 | 19.99 | 22.99 | abra-electronics (https://abra-electronics.com/opto-illumination/lcds-and-displays/graphic-tft/ard-lcd-2.4-2.4-lcd-tft-display-for-arduino-uno-mega.html) | Département génie électrique - ÉTS
Fusible | GMA/3A Fusible 3A/ Action Rapide | Protéger | 2 | 0.27 | 0.62 | abra-electronics (https://abra-electronics.com/electromechanical/circuit-protection/fuses/gma-fast-blow-20mm-x-5mm-european-fuses/gma-3a-mini-fast-blow-3-amp-fuse-20mm-x-5mm-gm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) | Acheté
Gyroscope | 6 DOF SENSOR - MPU6050 | Positionner | 1 | 19.35 | 22.25 | digikey (https://www.digikey.ca/fr/products/detail/dfrobot/SEN0142/6588492?s=N4IgTCBcDaIMoFEByAGAjAFggXQL5A) | Département génie électrique - ÉTS
LED | LED-STRIP-13-1M | Éclairer | 1 | 13.75 | 15.81 | abra-electronics.com (https://abra-electronics.com/opto-illumination/led-strips/5v-addressable/led-strip-13-1m-rgb-60-5050-leds-1-meter-strip-ws2812-individually-addressable-3-pin-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) | Département génie électrique - ÉTS
LIDAR | Capteur de Distance LIDAR 8m TF-Luna | Détection | 1 | 28.57 | 32.86 | robotshop (https://ca.robotshop.com/fr/products/capteur-distance-lidar-8m-tf-luna) | Département génie électrique - ÉTS
Microcontrôleur | ARDUINO UNO Q 2GB RAM 16GB EMMC | Traitement de données | 1 | 87.8 | 100.97 | digikey (https://www.digikey.ca/en/products/detail/arduino/ABX00162/27526619) | Département génie électrique - ÉTS | Hausse de prix 07/26
Porte Fusible | FH501 | Protéger | 1 | 1.53 | 1.76 | abra-electronics (https://abra-electronics.com/electromechanical/circuit-protection/fuseholders/fuse-block-fh501.html) | Acheté
Servo moteur | GK-SERVO-9G geeekus Servomoteur analogique 180 degrés 9G | Déplacer | 1 | 5.48 | 6.30 | abra-electronics (https://abra-electronics.com/electromechanical/motors/servo-motors/gk-servo-9g-180-geeekus-180-degrees-analog-servo-motor-9g.html) | Membre de l'équipe
USB 2.0 Breakout Board | BB-USB Platine à déploiement USB 2.0 femelle | Transmission | 1 | 2 | 2.30 | abra-electronics (https://abra-electronics.com/interconnects/connectors/usb/bb-usb-usb-2.0-female-breakout-board.html) | Acheté
Câble Dupont | Câbles de pontage | Connecter | 1 | 5.27 | 6.06 | abra-electronics (https://abra-electronics.com/wire-cable-accessories/wirecable/jumper-wire-assembly/single-row-2-54mm-0-1/jw-mm-20-6-jumper-wires-connected-6-m-m-20-pack-jw-mm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)
PCB | PCB | Conduction | 1 | 5.3 | 6.09 | jlcpcb (https://cart.jlcpcb.com/quote?spm=jlcpcb.Public.2006) | Département génie électrique - ÉTS | Fait par le département de génie élé, estimation de l'équivalence
Coque | Impression 3D en PLA | Structure | 1 | 6.89 | 7.92 | bambulab (https://ca.store.bambulab.com/fr/products/pla-basic-filament?id=43766892298480) | Membre de l'équipe
Total |  |  |  |  | 486.20
*Ne comprends pas les frais de douane et d'expédition. Prix en CAD

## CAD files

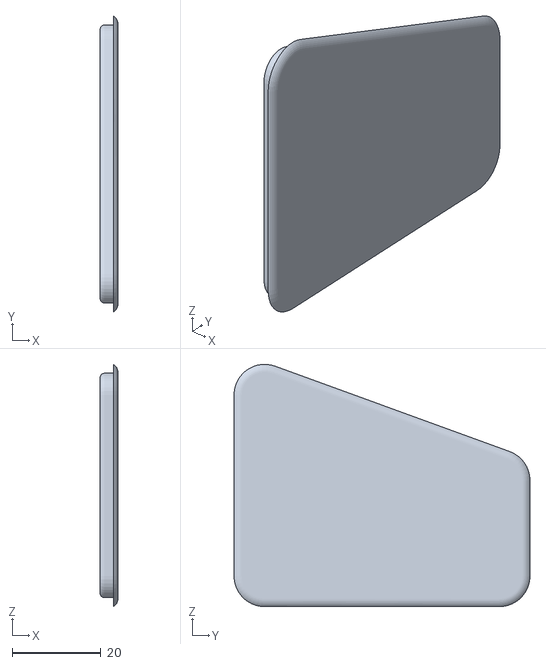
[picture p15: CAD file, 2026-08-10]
hardware/3D_Chassis/window.STL
4.00 x 66.6 x 54.5

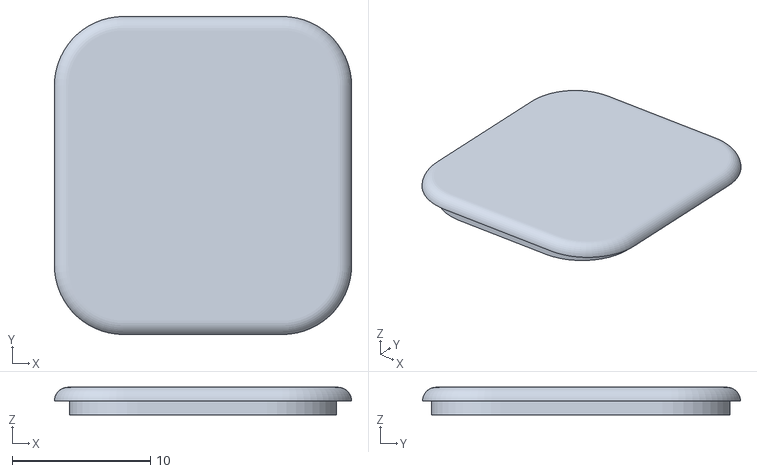
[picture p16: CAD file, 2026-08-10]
hardware/3D_Chassis/blinker_w_gap.STL
21.5 x 23.0 x 2.00

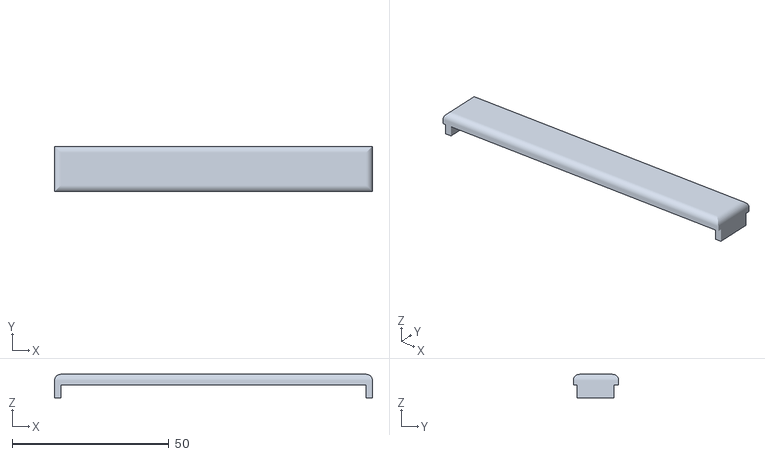
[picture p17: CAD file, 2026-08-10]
hardware/3D_Chassis/headlight_w_gap.STL
101.5 x 14.5 x 7.50

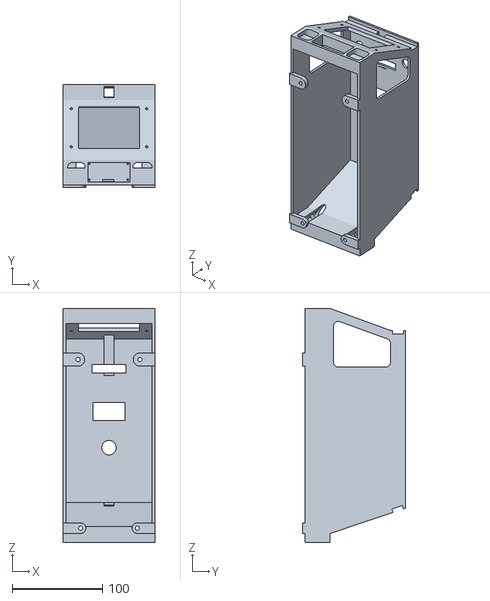
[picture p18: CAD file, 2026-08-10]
hardware/3D_Chassis/TankuChanCockpitWithoutServoCage_V3.STL
101.5 x 114.1 x 259.2

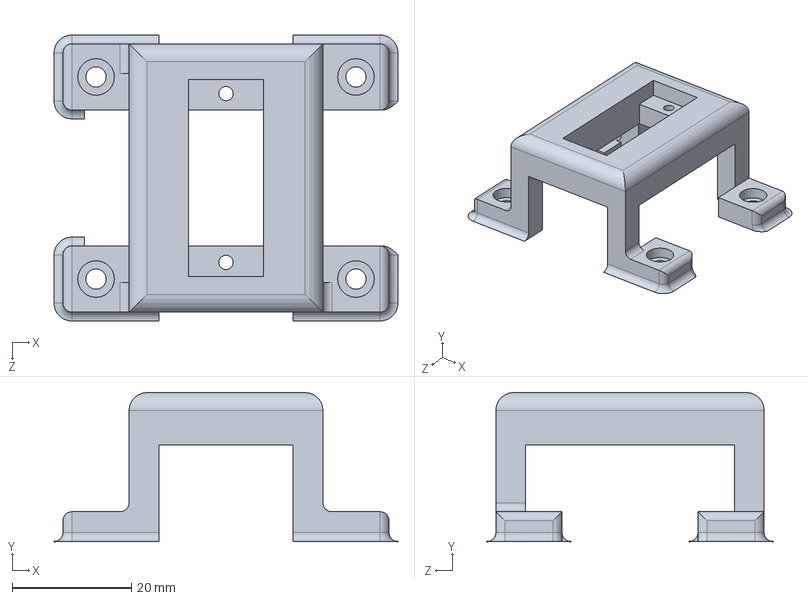
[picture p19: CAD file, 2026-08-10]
hardware/3D_Chassis/ServoCage.SLDPRT
57.7 x 25.0 x 48.0 mm

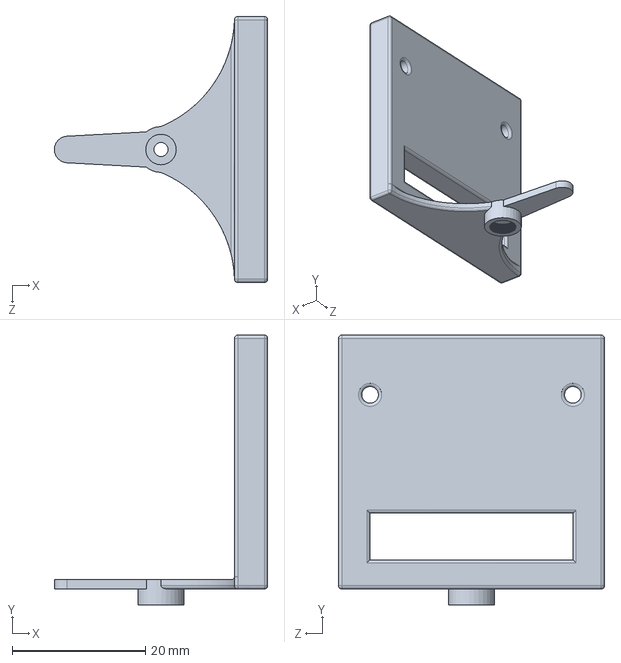
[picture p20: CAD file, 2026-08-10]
hardware/3D_Chassis/SG90 - Micro Servo 9g - Tower Pro.3.SLDPRT
32.1 x 40.6 x 40.0 mm

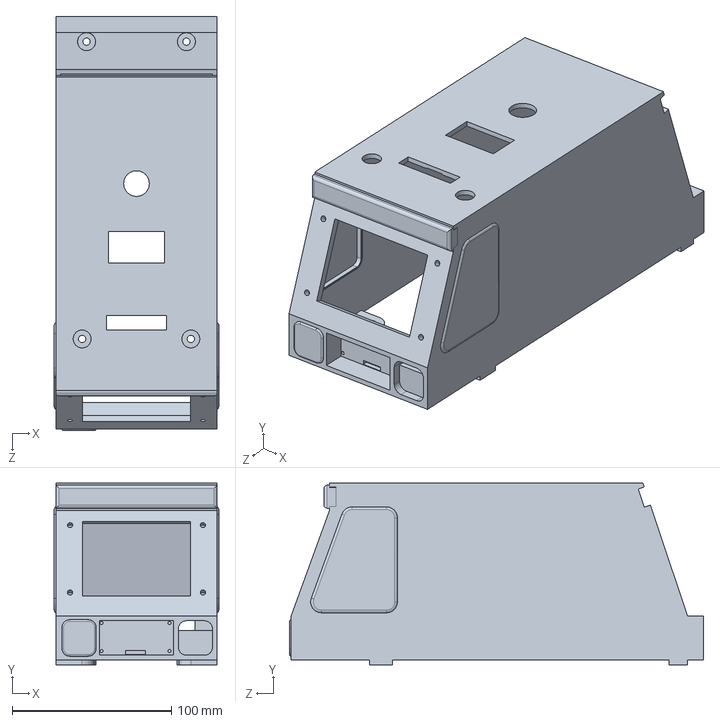
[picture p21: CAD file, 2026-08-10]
hardware/3D_Chassis/body_vlad.SLDPRT
103.5 x 114.1 x 260.2 mm

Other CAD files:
hardware/3D_Chassis/window 2.STL

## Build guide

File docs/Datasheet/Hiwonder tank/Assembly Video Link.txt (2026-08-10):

Double Layer Track Chassis Assembly：https://youtu.be/bknJQQXvkq0

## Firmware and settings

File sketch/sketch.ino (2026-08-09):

#include <Wire.h>
#include "Arduino_RouterBridge.h"
#include "config.h"
#include "bus_i2c.h"
#include "moteurs.h"
#include "imu.h"
#include "deplacement.h"
#include "leds.h"
#include "ecran.h"
#include "ultrason.h"
#include "lidar.h"
#include "comm_bridge.h"
#include "servo_lidar.h"
#include "obstacle.h"
#include "securite.h"
#include "evitement.h"
#include "test_capteurs.h"


// ======================== LEDs ========================

static void rpc_mode_bandeaux(int mode) { Leds_DefinirModeBandeaux(mode); }
static void rpc_mode_phares(int actif)  { Leds_DefinirPhares(actif); }

// ======================== Mode de conduite ========================

static void rpc_definir_mode(int mode) { Securite_DefinirMode(mode); }
static int  rpc_veto_actif(void)       { return Securite_VetoActif() ? 1 : 0; }

// 0 : rien, 1 : obstacle, 2 : feu. Le Bridge ne transmettant pas de valeur
// negative, l'absence de cause est codee par zero.
static int rpc_cause_arret(void) {
    if (Securite_ObstacleBloquant()) return 1;
    if (Securite_FeuBloquant())      return 2;
    return 0;
}

// ======================== Capteurs de distance ========================

static int rpc_lire_ultrason_cm(void) { return Ultrason_DistanceCm(); }
static int rpc_lire_lidar_cm(void)    { return Lidar_DistanceCm(); }

// ======================== ServoMoteur ========================

static void rpc_servo_angle(int angle) { ServoLidar_DefinirAngle(angle); }

// ======================== Detection d'obstacles ========================

static int rpc_obstacle_frontal_cm(void) { return Obstacle_DistanceFrontaleCm(); }
static int rpc_obstacle_detecte(void)    { return Obstacle_EstDetecte() ? 1 : 0; }
static int rpc_lancer_sondage(void)      { Obstacle_LancerSondage(); return 1; }

// 0 : sondage en cours, resultat pas encore disponible. Le Bridge ne
// transmet pas de valeur negative, d'ou l'encodage 1 = gauche, 2 = droite.
static int rpc_cote_degage(void) {
    if (Obstacle_SondageEnCours()) return 0;
    return (Obstacle_CoteLePlusDegage() == SECTEUR_GAUCHE) ? 1 : 2;
}

// ======================== Setup ========================

void setup() {

    Serial.begin(9600);
    Wire1.begin();
    delay(500);

    // Bridge en premier : le controle survit a un capteur defaillant
    CommBridge_Initialiser();
    Bridge.provide_safe("joy_x",               Deplacement_JoystickX);
    Bridge.provide_safe("joy_y",               Deplacement_JoystickY);
    Bridge.provide_safe("roues",               Deplacement_Roues);
    Bridge.provide_safe("avancer_metres",      Deplacement_AvancerMetres);
    Bridge.provide_safe("reculer_metres",      Deplacement_ReculerMetres);
    Bridge.provide_safe("tourner_gauche_deg",  Deplacement_TournerGauche);
    Bridge.provide_safe("tourner_droite_deg",  Deplacement_TournerDroite);
    Bridge.provide_safe("arreter_mouvement",   Deplacement_Arreter);
    Bridge.provide_safe("mouvement_actif",     Deplacement_EstActif);
    Bridge.provide_safe("definir_mode",        rpc_definir_mode);
    Bridge.provide_safe("veto_actif",          rpc_veto_actif);
    Bridge.provide_safe("cause_arret",         rpc_cause_arret);
    Bridge.provide_safe("mode_bandeaux",       rpc_mode_bandeaux);
    Bridge.provide_safe("mode_phares",         rpc_mode_phares);
    Bridge.provide_safe("lire_ultrason_cm",    rpc_lire_ultrason_cm);
    Bridge.provide_safe("lire_lidar_cm",       rpc_lire_lidar_cm);
    Bridge.provide_safe("servo_angle",         rpc_servo_angle);
    Bridge.provide_safe("obstacle_frontal_cm", rpc_obstacle_frontal_cm);
    Bridge.provide_safe("obstacle_detecte",    rpc_obstacle_detecte);
    Bridge.provide_safe("lancer_sondage",      rpc_lancer_sondage);
    Bridge.provide_safe("cote_degage",         rpc_cote_degage);

    // Sonde le bus une fois : les modules dont le peripherique est absent
    // resteront inertes au lieu de bloquer la boucle sur des timeouts I2C.
    BusI2C_Scanner();

    Moteurs_Initialiser();
    Imu_Initialiser();
    Imu_Calibrer();
    Leds_Initialiser();
    Ecran_Initialiser();
    Ecran_AfficherConnexion(RESEAU_SSID, RESEAU_MOT_DE_PASSE, RESEAU_IP);
    Ultrason_Initialiser();
    Lidar_Initialiser();
    ServoLidar_Initialiser();
    Obstacle_Initialiser();
    Securite_Initialiser();
    Evitement_Initialiser();

    Securite_Arreter();
}

// ======================== Loop ========================

// Bilan de demarrage, emis depuis loop() : le moniteur serie s'attache
// apres l'execution de setup().
static void tracerDemarrage(void) {
    static bool tracee = false;
    if (tracee || millis() < 3000) return;
    tracee = true;

    BusI2C_Tracer();
    Serial.println("[MCU] VTA pret, Bridge actif");
}

void loop() {
    Bridge.update();
    Deplacement_MettreAJour();

    // Les LEDs affichent, elles n'interrogent pas le deplacement : la
    // direction du clignotant leur est fournie ici.
    Leds_DefinirVirage(Deplacement_DirectionVirage());
    Leds_MettreAJour();
    Ultrason_MettreAJour();
    Lidar_MettreAJour();
    ServoLidar_MettreAJour();
    Obstacle_MettreAJour();
    Evitement_MettreAJour();
    tracerDemarrage();
    TestCapteurs_MettreAJour();
}

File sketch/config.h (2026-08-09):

#ifndef CONFIG_H
#define CONFIG_H

// Adresses I2C (bus Wire1 / Qwiic)
#define ADRESSE_MOTEUR        0x34
#define ADRESSE_GYRO          0x68
#define ADRESSE_LIDAR         0x10

// Registres carte moteur Hiwonder. Adresses et unites reprises de l'exemple
// officiel du fabricant, fourni avec les moteurs a encodeur.
#define REG_TYPE_MOTEUR       20      // 0x14 : type de moteur a encodeur
#define REG_POLARITE_ENCODEUR 21      // 0x15 : polarite du sens de comptage
#define REG_PWM_FIXE          31      // 0x1F : PWM fixe, boucle ouverte (-100 a 100)
#define REG_VITESSE_FIXE      51      // 0x33 : vitesse fixe, boucle fermee
#define REG_ENCODEUR_TOTAL    60      // 0x3C : impulsions cumulees des 4 canaux

// JGB37-520 12V 110RPM : 44 impulsions par tour d'aimant, reduction 90.
#define TYPE_JGB37_520        3

// Registres MPU-6050
#define REG_PWR_MGMT_1        0x6B
#define REG_SMPRT_DIV         0x19    // diviseur de cadence d'echantillonnage
#define REG_CONFIG            0x1A    // filtre passe-bas numerique (DLPF)
#define REG_GYRO_CONFIG       0x1B    // pleine echelle du gyroscope
#define REG_GYRO_ZOUT_H       0x47    // axe Z seul, 2 octets
#define SENSIBILITE_GYRO      131.0   // LSB par deg/s a pleine echelle +/-250

// Le capteur demarre avec 256 Hz de bande passante, tres au-dela de ce que le
// chassis produit : on n'integre alors que la vibration des chenilles. La
// valeur 4 ramene la bande a 20 Hz, sous la moitie de la cadence de lecture.
#define DLPF_20HZ             4
#define SMPRT_DIV_200HZ       4       // 1000 / (1 + 4) = 200 Hz interne

// Calibration du zero. La version longue sert au demarrage, la courte est
// rejouee avant chaque mouvement asservi, le vehicule etant alors immobile.
#define IMU_CAL_ECHANTILLONS        200
#define IMU_CAL_ECHANTILLONS_RAPIDE 40
#define IMU_CAL_DISPERSION_MAX      3.0f  // deg/s : au-dela, le vehicule bougeait

// Calibration mecanique. DIAMETRE_ROUE_MM et RATIO_REDUCTEUR n'interviennent
// que par leur produit dans Moteurs_PulsesEnMetres, et le glissement de la
// chenille s'y cache : ce sont des constantes ajustees par la mesure, pas des
// grandeurs physiques relevables sur une fiche produit.
//
// NON CALIBRE : RATIO_REDUCTEUR est la valeur d'origine, jamais mesuree. Le
// fabricant annonce 90 pour le JGB37-520, mais cette valeur donne le double de
// la distance reelle sur ce chassis, ce qui situe le rapport effectif autour de
// 45. Les distances des sequences de blocs sont donc justes a quelques pourcents
// pres au mieux.
// Reglage : RATIO_nouveau = RATIO_actuel * (distance_commandee / mesuree),
// sur 2 m pour limiter le poids des transitoires de demarrage et d'arret.
#define DIAMETRE_ROUE_MM      65.0
#define RATIO_REDUCTEUR       50.0
#define IMPULSIONS_PAR_TOUR   44.0
#define IMPULSIONS_PAR_ROUE   (IMPULSIONS_PAR_TOUR * RATIO_REDUCTEUR)

// Vitesses moteur (consignes). En boucle fermee, l'unite est le nombre
// d'impulsions par 10 ms : la plage utile va jusqu'a environ 50 selon la
// charge et la tension. La translation reprend la valeur de l'exemple du
// fabricant. La rotation est volontairement bien en dessous : l'inertie de fin
// de virage croit comme le carre de la vitesse, et la reproductibilite compte
// davantage que la rapidite sur un parcours.
#define VITESSE_DEPLACEMENT   12
#define VITESSE_ROTATION      11

// Pilotage manuel au joystick. Reponse lineaire, une seule sensibilite pour la
// translation et la rotation.
#define VITESSE_JOYSTICK      80

// Compensation de l'inertie de fin de rotation, valeurs retenues pour
// VITESSE_ROTATION = 11. Toute modification de cette vitesse impose de les
// reprendre : commander 90 puis 180 degres et mesurer. Un ecart constant
// designe l'inertie, donc ROT_MARGE_ARRET_DEG ; un ecart proportionnel designe
// SENSIBILITE_GYRO. Garder ROT_MARGE_LENTE_DEG nettement au-dessus de la marge
// d'arret, sans quoi la phase d'approche lente n'a plus lieu.
#define ROT_MARGE_ARRET_DEG   10.0
#define ROT_MARGE_LENTE_DEG   20.0

// Repetition de la consigne moteur pendant un mouvement asservi (ms)
#define REEMISSION_MOTEUR_MS  100
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

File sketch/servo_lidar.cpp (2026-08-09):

#include "servo_lidar.h"
#include "config.h"

static int angleCourant = SERVO_ANGLE_CENTRE;
static int angleCible   = SERVO_ANGLE_CENTRE;

static bool          cibleAtteinte = false;
static unsigned long tArriveeCible = 0;

void ServoLidar_Initialiser(void) {
    pinMode(PIN_SERVO, OUTPUT);
    digitalWrite(PIN_SERVO, LOW);
    angleCourant  = SERVO_ANGLE_CENTRE;
    angleCible    = SERVO_ANGLE_CENTRE;
    // Laisse le premier passage ouvrir la fenetre de maintien, le temps
    // d'amener physiquement le support au centre.
    cibleAtteinte = false;
    tArriveeCible = 0;
}

void ServoLidar_DefinirAngle(int angle) {
    angleCible = constrain(angle, SERVO_ANGLE_MIN, SERVO_ANGLE_MAX);
}

// Convertit un angle (0-180 deg) en largeur d'impulsion (us).
static int angleEnMicros(int angle) {
    return map(angle, SERVO_ANGLE_MIN, SERVO_ANGLE_MAX,
               SERVO_PULSE_MIN_US, SERVO_PULSE_MAX_US);
}

// PWM logiciel : avance vers la cible + rafraichit l'impulsion a 50 Hz.
// L'impulsion est mesuree avec micros() (attente active) : le scheduler
// Zephyr ne garantit pas la precision de delayMicroseconds(), ce qui
// provoque un tremblement du servo.
void ServoLidar_MettreAJour(void) {
    static unsigned long tRafraichi = 0;
    static unsigned long tDegre     = 0;

    unsigned long maintenant = millis();

    // Mouvement progressif vers la cible
    if (angleCourant != angleCible) {
        if (maintenant - tDegre >= SERVO_MS_PAR_DEGRE) {
            tDegre = maintenant;
            angleCourant += (angleCible > angleCourant) ? 1 : -1;
        }
        cibleAtteinte = false;
    } else if (!cibleAtteinte) {
        cibleAtteinte = true;
        tArriveeCible = maintenant;
    }

    // Le train d'impulsions s'arrete une fois la position tenue. A l'arret,
    // chaque impulsion regeneree porte le jitter de l'attente active et
    // redemande donc une position legerement differente : le servo vibre sur
    // place sans se deplacer. Sans signal, le reducteur maintient l'angle,
    // la charge du support etant faible.
    if (cibleAtteinte && (maintenant - tArriveeCible) >= SERVO_MAINTIEN_MS) {
        return;
    }

    // Impulsion toutes les 20 ms (50 Hz)
    if (maintenant - tRafraichi >= 20) {
        tRafraichi = maintenant;
        unsigned long largeur = (unsigned long)angleEnMicros(angleCourant);
        digitalWrite(PIN_SERVO, HIGH);
        unsigned long t0 = micros();          // apres le front : exclut la latence GPIO
        while (micros() - t0 < largeur) { }   // attente active, timing precis
        digitalWrite(PIN_SERVO, LOW);
    }
}

int ServoLidar_AngleActuel(void) { return angleCourant; }
bool ServoLidar_EstEnMouvement(void) { return angleCourant != angleCible; }

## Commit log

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2026-06-30 Ajout du module de vision (caméra, YOLO, détection routière)
    - Ajout de vision.py : capture caméra USB, détection de feux de
    signalisation (YOLOv8n ONNX), classification couleur HSV,
    détection de lignes de route (Canny + Hough)
    - Ajout de boucle_vision.py : orchestration des détections à cadences
    indépendantes (~3 Hz feux, ~10 Hz lignes) avec anti-rebond
    - Ajout de comm_bridge.py : notifications Bridge RPC vers le MCU
    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
2026-07-01 fix: Wire1, ports 7000, pip auto-install
    [sketch.ino]
2026-07-01 fix: inversion axe X joystick
    [sketch.ino]
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2026-07-05 Refactoring interface web : structure modulaire et conventions
    - Deplacement de l'interface vers assets/ (HTML, CSS, JS separes)
    - Extraction du JS inline vers assets/app.js
    - Correction des IDs HTML en kebab-case (convention projet)
    - Creation de serveur_web.py (Flask + SocketIO, sequences Blockly)
    - Creation de comm_bridge.py (couche communication Bridge unifiee)
    - Reduction de main.py a un point d'entree minimal (3 lignes)
    - Suppression du pip install en runtime
    - Chargement des Google Fonts via CDN
    Code adapte de la branche Vlad (mode manuel + blocs fonctionnel).
    Structure reorganisee pour permettre l'integration des modules
    vision, navigation et moteurs en PRs separees.
2026-07-05 Sketch minimal Bridge + moteurs et auto-install dépendances Python
    - sketch.ino : initialisation Bridge RPC, handlers joystick/moteurs/LEDs,
    pilotage manuel différentiel, machine à états basique (sans asservissement)
    - main.py : installation automatique des requirements au démarrage du conteneur
    - .gitignore : ajout .venv/
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2026-07-06 Refactoring sketch modulaire : moteurs, IMU, deplacement asservi
    - config.h : constantes hardware (I2C, calibration, timeouts)
    - moteurs.h/cpp : carte Hiwonder, encodeurs, I2C bas niveau
    - imu.h/cpp : MPU-6050 gyroscope, calibration offset
    - deplacement.h/cpp : machine a etats non-bloquante, joystick,
    asservissement encodeurs (avance) et gyro (rotation)
    - sketch.ino : reduit a setup/loop et enregistrement Bridge
    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
2026-07-15 Update README steps for Arduino Uno Q configuration en mode point d'accès
2026-07-15 Update README with Arduino access point setup
    Added instructions for configuring Arduino UNO Q as an access point.
2026-07-15 Correction vision, navigation et Blockly
    - vision.py : fix doublon moments(), retirer debug print,
    seuil detection par countNonZero au lieu de m00
    - navigation.py : filtre anti-spam Bridge (envoie seulement
    quand la correction change)
    - serveur_web.py : ping_timeout=60, import time/navigation,
    _mouvement_bloquant avec eventlet.tpool et timeout 10s,
    joystick bloque en mode autonome, activation navigation
    sur changement de mode
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2026-07-20 Fixes audit : resilience et bug boucle LEDs
    - sketch.ino : loop appelle Leds_MettreAJour (au lieu de
    Leds_Initialiser qui bloquait 2s et n'animait jamais)
    - sketch.ino : Bridge initialise en premier dans setup, avant
    les capteurs (le controle survit a un capteur I2C defaillant)
    - main.py : install pip dans try/except (le serveur demarre
    meme hors ligne / mode point d'acces)
    - serveur_web.py : garde try/except autour du traitement vision
    (une erreur de frame ne tue plus la tache)
    [sketch.ino]
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2026-07-20 Integration LEDs WS2812B + nettoyage code de test
    - leds.h/cpp : driver NeoPixel (gyrophare, clignotant, phares)
    - config.h : broches et parametres bandeaux LED
    - sketch.ino : init Leds + handlers Bridge mode_led1/2,
    Bridge enregistre avant les capteurs (resilience)
    - sketch.yaml : Adafruit NeoPixel 1.15.5 (seule version
    compatible avec le core Zephyr de l'UNO Q)
    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
2026-07-20 Ajout module ecran ILI9341 : bonhomme souriant
    - ecran.h/cpp : init TFT (SPI materiel, paysage) + visage souriant
    - config.h : broches ecran (CS/DC/RST), PIN_BANDEAU_2 sur D7
    pour liberer D9 (DC ecran)
    - sketch.ino : init ecran dans setup
    - sketch.yaml : Adafruit GFX 1.12.6 + ILI9341 1.6.3 + BusIO 1.17.4
    (BusIO 1.17.4 requis : desactive le fast-pinio incompatible Zephyr
    [config.h, sketch.ino]
2026-07-21 Ajout capteur ultrason HC-SR04
    - ultrason.h/cpp : mesure de distance frontale par pulseIn
    (impulsion trigger + duree d'echo), cache non bloquant
    rafraichi ~10 Hz dans loop
    - config.h : broches TRIG=D2, ECHO=D3 (libres, evite le SPI
    ecran sur D11/D12), portee et periode
    - sketch.ino : init + Ultrason_MettreAJour en loop, RPC
    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
2026-07-22 Validation ultrason HC-SR04 + retrait du code de test
    - Mesure de distance validee sur hardware (pont diviseur 22k/47k
    sur ECHO pour ramener le 5V a ~3.3V)
    - Retrait du bloc de debug Serial dans loop()
2026-07-22 Ajout LiDAR TF-Luna (I2C) — distance frontale
    - lidar.h/cpp : lecture I2C du TF-Luna sur Wire1/Qwiic (0x10),
    validation des mesures (force min, saturation, portee),
    cache non bloquant rafraichi ~10 Hz dans loop
    - config.h : adresse, registre, seuils et periode LiDAR
    - sketch.ino : init + Lidar_MettreAJour en loop, RPC
    lire_lidar_cm exposee au Bridge
    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
2026-07-22 Ajout servo de balayage LiDAR (non bloquant)
    Ajout servo de balayage LiDAR (non bloquant)
    - servo_lidar.h/cpp : machine a etats non bloquante, avance 1 deg
    par tranche de temps (ServoLidar_DefinirAngle/MettreAJour),
    remplace la boucle delay() bloquante du code d'origine
    - config.h : broche D5 (D9 occupe par le DC ecran), angles et cadence
    - sketch.ino : init + ServoLidar_MettreAJour en loop, RPC
    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
2026-07-22 Servo LiDAR sans librairie : PWM logiciel (evite conflit NeoPixel)
    Servo LiDAR sans librairie : PWM logiciel (evite conflit NeoPixel)
    - servo_lidar.cpp : generation PWM 50 Hz par bit-bang (impulsion
    0.5-2.5 ms toutes les 20 ms), mouvement progressif non bloquant
    - config.h : largeurs d'impulsion min/max
    - sketch.yaml : retrait de la lib Servo (1.3.0)
    - sketch.ino : retrait du shim noInterrupts/interrupts
    La lib Servo d'Arduino desactive les interruptions et casse le
    show() de NeoPixel au link sur le core Zephyr. Le PWM logiciel
    supprime le conflit a la racine (compromis : leger jitter servo).
    [config.h, servo_lidar.cpp, sketch.ino]
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2026-07-26 Scan I2C au demarrage : modules inertes si peripherique absent
    Un peripherique absent faisait partir chaque transaction en timeout, ce qui
    bloquait la boucle et cassait le PWM logiciel du servo. Imu_Calibrer bloquait
    a lui seul setup() pendant plus d'une seconde (200 lectures + delay).
    Nouveau module bus_i2c : sonde une fois les adresses connues apres Wire1.begin()
    et met le resultat en cache. Moteurs, IMU et LiDAR interrogent ce cache au lieu
    de sonder eux-memes. L'ultrason garde sa detection par impulsion ECHO (non I2C).
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2026-07-26 Servo de balayage LiDAR fonctionnel (PWM logiciel, SG90 sur D5)
    git commit -F- <<'EOF'
    Servo de balayage LiDAR fonctionnel (PWM logiciel, SG90 sur D5)
    PWM logiciel plutot que la librairie Servo, incompatible avec NeoPixel sur
    le core Zephyr. Impulsion mesuree par attente active sur micros() : le
    scheduler Zephyr rend delayMicroseconds() imprecis et le servo tremblait.
    Deux blocages empechaient loop() de tourner assez vite pour maintenir le
    train d'impulsions :
    - pulseIn interprete son timeout en ms sur ce core, pas en us : le sondage
    de l'ultrason bloquait setup() 60 s au lieu de 60 ms.
    - Chaque peripherique I2C absent partait en timeout. Nouveau module bus_i2c
    qui sonde le bus une foi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
    [bus_i2c.cpp, sketch.ino]
2026-07-29 Module de test : releve serie des capteurs de distance
    Affiche toutes les 500 ms la distance ultrason et lidar ainsi que l'angle
    du servo, pour verifier l'integration des capteurs entre eux. Desactivable
    en commentant TEST_CAPTEURS_ACTIF dans test_capteurs.h : la fonction devient
    un stub vide, sketch.ino reste inchange.
    Ajout de Ultrason_EstPresent pour distinguer un capteur absent d'une mesure
    invalide, par coherence avec Lidar/Imu/Moteurs_EstPresent.
    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
2026-07-31 Detection d'obstacles : fusion ultrason + LiDAR
    Nouveau module obstacle qui combine les deux capteurs de distance selon le
    regime ou leur datasheet les donne fiables. La plus petite des mesures
    valides l'emporte : une cible vue par un seul capteur suffit a la signaler.
    Le TF-Luna ne convient pas a une carte d'obstacles. Son FOV de 2 degres
    donne un spot de 3,5 cm a 1 m, alors que deux mesures espacees de 15 degres
    sont distantes de 26 cm : 87 % de la scene ne serait jamais echantillonnee.
    Sa zone morte de 20 cm lui interdit par ailleurs le role de capteur de
    securite. Le HC-SR04 assure donc la detection de presence (cone large, voit
    des 2 cm) et le TF-Luna la telemetrie.
    Le servo ne balaye p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
    [config.h, lidar.cpp, obstacle.cpp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]
2026-07-31 Detection d'obstacles : fusion ultrason + LiDAR
    Servo : le train d'impulsions s'arrete apres SERVO_MAINTIEN_MS une fois la
    cible atteinte. A l'arret, chaque impulsion regeneree portait le jitter de
    l'attente active et redemandait une position legerement differente, ce qui
    faisait vibrer le servo sur place. L'instant de reference de l'impulsion est
    aussi pris apres le front montant, la latence du GPIO etant auparavant
    comptee dans la largeur.
    Autres changements :
    - ULTRASON_RECUL_CM et LIDAR_RECUL_CM ramenent les deux mesures au pare-choc
    avant, reference commune. A renseigner sur la coque finale, les capteurs
    n'y etant pas superposes. La correction est faite dans la couche de fusion,
    l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
    [config.h, obstacle.cpp, servo_lidar.cpp]
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2026-08-02 Suivi de ligne : correcteur proportionnel-derive
    Suivi de ligne : correcteur proportionnel-derive
    Le suivi purement proportionnel oscillait d'un bord a l'autre jusqu'a perdre
    la ligne. La cause est le retard de la boucle : la vision tourne a 10 Hz et
    le Bridge puis les moteurs ajoutent leur latence, si bien que la correction
    arrive alors que l'ecart a deja change de signe. Un correcteur proportionnel
    ne peut que reagir a un ecart deja constitue, jamais l'anticiper.
    Ajout d'un terme derive, qui s'oppose aux variations de l'ecart et non a
    l'ecart lui-meme : il freine la correction pendant que le vehicule revient
    vers la ligne, ce qui supprime le depassement.
    Ajout d'une zone morte. Le centroid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
2026-08-04 Mode blocks - Fix
    Mode blocs : fiabilisation rotations/avances et stabilite Bridge
    - deplacement.cpp : re-emission commande moteur a chaque iteration
    (glitch I2C rattrape), plafond du pas d'integration gyro et duree
    minimale de rotation (anti-saut instantane)
    - config.h : ajout ROT_TEMPS_MIN_MS
    - serveur_web.py : pause vision/camera/flux video pendant une sequence
    (evite la saturation CPU qui corrompait la trame Bridge) ; confirmation
    de demarrage et attente robuste dans _mouvement_bloquant
    - comm_bridge.py : mouvement_actif_brut() distingue lecture ratee (None)
    d'un mouvement termine (0)
    [config.h]
2026-08-06 Mouvements asservis : marge d'arret plafonnee et re-emission cadencee
    Affine le correctif de Vlad sur le mode blocs. Son coeur est conserve tel
    quel : distinguer une lecture Bridge ratee d'un mouvement termine, et
    confirmer le demarrage avant d'attendre la fin.
    La duree minimale de rotation traitait un symptome dont la cause etait la
    condition d'arret elle-meme. ROT_MARGE_ARRET_DEG vaut 10 degres et etait
    soustraite sans garde-fou de la cible : pour une consigne de 10 degres, la
    condition devenait "angleCumule >= 0", vraie des le premier passage, et la
    rotation se terminait avant d'avoir commence ; pour 20 degres elle s'arretait
    a mi-course. La marge est desormais annulee quand elle depasser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
    [config.h]
2026-08-06 Retrait de l'ancienne interface Flask
    Les dossiers python/static et python/templates datent d'avant le passage a
    assets/ et sont revenus par le merge de la branche Vlad. serveur_web.py sert
    assets/ et rien d'autre : aucun render_template, aucune reference a ces
    dossiers dans le code Python, Flask ne les regarde jamais.
    Leur contenu est perime autant que duplique. L'ancienne page ne connait ni
    mode-bandeaux ni toggle_phares, donc plus rien de la refonte des LEDs, et les
    librairies Blockly et Socket.IO y sont vendues une seconde fois.
    3736 lignes en moins dans le depot, et plus de risque qu'un coequipier edite
    la mauvaise interface.
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2026-08-07 Trim de derive fractionnaire et rapport de reduction mesure
    Le rapport annonce par Hiwonder pour le JGB37-520, 90, donne le double de la
    distance reellement parcourue sur ce chassis. Le releve des encodeurs situe le
    rapport effectif vers 45. La valeur d'origine, 50, etait donc plus proche du
    vrai que la correction precedente.
    Le commentaire precise ce que sont reellement ces constantes.
    DIAMETRE_ROUE_MM et RATIO_REDUCTEUR n'interviennent que par leur produit dans
    Moteurs_PulsesEnMetres, et le glissement de la chenille s'y cache : ce sont des
    constantes ajustees par la mesure, pas des grandeurs physiques relevables sur
    une fiche produit. La formule de reglage est donnee sur place.
    Le decalage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
    [config.h]
2026-08-07 IMU : filtre passe-bas, lecture ciblee et rezero avant chaque mouvement
    Le MPU-6050 demarrait sur ses valeurs par defaut, soit 256 Hz de bande
    passante, alors que le chassis ne tourne qu'a quelques degres par seconde.
    L'integration accumulait donc surtout la vibration des chenilles, qu'aucun
    reglage en aval ne peut distinguer d'un vrai virage. Le filtre passe-bas
    interne est configure a 20 Hz, sous la moitie de la cadence de lecture, et la
    cadence interne du capteur a 200 Hz. La pleine echelle est fixee
    explicitement a plus ou moins 250 degres par seconde, la plus sensible, au
    lieu d'etre supposee.
    La lecture ne prend plus que l'axe Z, deux octets au lieu des six de la rafale
    complete dont q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
    [config.h, imu.cpp]
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2026-08-08 Correction du sens des secteurs et champ de vision de la camera
    OBSTACLE_SENS_SERVO passe a -1, valide par l'essai : un obstacle place a
    droite du vehicule ressortait dans le secteur gauche. La constante n'avait
    jamais ete verifiee depuis l'ecriture du sondage, et le mode autonome en
    dependait entierement puisque c'est elle qui determine de quel cote le
    contournement s'engage.
    VITESSE_ROTATION descend de 20 a 11 pour reprendre les depassements d'environ
    quinze degres. L'energie a dissiper croit comme le carre de la vitesse, donc
    ralentir la rotation reduit l'inertie a la source plutot que de la compenser
    par une marge d'arret toujours plus grande. Une rotation n'a pas besoin d'etre
    rapide, e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
    [config.h]
2026-08-08 Capture en 640x360 a 30 images par seconde
    L'enumeration des modes de la camera montre que le capteur plafonne a
    1280x720 : il n'existe aucun mode 1080p, ni en YUYV ni en MJPG. Le champ
    obtenu en 720p est donc deja le champ complet, et le zoom residuel vient de
    l'objectif. Aucun reglage logiciel n'y changera quoi que ce soit.
    La meme enumeration revele un plafond plus genant : en YUYV, le 1280x720 est
    limite a dix images par seconde. Or PERIODE_LIGNES vaut 0,10 s, donc le suivi
    de ligne consommait exactement une image par cycle de correction, sans aucune
    marge. Une image perdue devenait un cycle sans mesure, et le terme derive du
    correcteur travaillait sur des echantillons irreguliers.
    Le mo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
2026-08-08 Sortir les emissions et les appels Bridge des threads du pool
    Corrige la cause des deconnexions du navigateur, des coupures du flux video et
    de la corruption des trames RPC. Les trois symptomes partagent une seule
    origine.
    eventlet.tpool.execute sort du modele cooperatif : la fonction s'execute dans
    un vrai thread systeme. Or BoucleVision.traiter y appelait ses callbacks, qui
    faisaient socketio.emit et comm_bridge.notifier_lignes. Emettre sur une socket
    verte depuis un thread qui n'est pas la boucle d'evenements peut corrompre le
    cadrage WebSocket : le navigateur ferme la connexion et se reconnecte une
    seconde plus tard. Le flux video passant par la meme connexion, il sautait
    avec elle. Et l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
2026-08-08 Contournement : arret explicite entre chaque etape
    Le vehicule ne s'immobilisait jamais a la detection. Il enchainait le sondage
    puis la rotation en roulant encore, les deux mouvements se superposant.
    La cause tient en une ligne de deplacement.cpp : des que le drapeau de
    manoeuvre est pose, Deplacement_Roues retourne sans rien envoyer. Or la carte
    Hiwonder regule en boucle fermee et maintient sa derniere consigne tant qu'on
    ne lui en donne pas d'autre. Le suivi de ligne cessait donc d'emettre, mais
    personne ne disait aux chenilles de s'arreter : le veto refuse les commandes
    d'avance, il n'en emet aucune.
    Un etat de pause est intercale avant chaque etape. Il coupe les moteurs, laisse
    EVITEMEN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
    [config.h]
2026-08-08 Detection des feux par fenetres a resolution native
    L'entree du modele YOLOv8n exporte en ONNX est figee a 256 pixels de cote.
    L'image entiere y etait redimensionnee, ce qui divisait la largeur apparente
    des objets par plus de deux : un feu de six centimetres vu a un metre passait
    d'environ trente-trois pixels a treize, sous le seuil de detection fiable du
    modele. D'ou un feu vu seulement au dernier moment, quand il etait deja dans
    le cone de l'ultrason.
    Le modele recoit desormais des fenetres prelevees a la resolution native. Deux
    fenetres, aux bords gauche et droit de l'image : le feu borde la chaussee et
    n'apparait jamais au centre du champ. Elles sont prises dans le haut de
    l'image, ou s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
2026-08-08 Detection de ligne et inference des feux en boucles separees
    Les deux traitements partageaient un appel synchrone unique. La detection de
    ligne, qui coute quelques millisecondes et pilote le vehicule, attendait donc
    derriere l'inference des feux, qui en coute plusieurs centaines. La cadence de
    correction du suivi de ligne etait celle de YOLO, pas la sienne.
    Le defaut n'etait pas seulement une cadence trop basse, mais le fait qu'elle
    dependait du cout de la vision : passer la detection des feux a deux fenetres
    a fait tomber le suivi de ligne de 5,7 a 2 Hz sans que navigation.py soit
    touche, invalidant au passage son reglage. Une modification de la vision
    degradait la trajectoire du vehicule.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
2026-08-08 Suivi de ligne cadence a l'echeance plutot qu'a la duree
    La boucle dormait PERIODE_LIGNES apres son travail, dont la duree s'ajoutait
    donc a la periode : trente-trois millisecondes de traitement et d'echanges
    Bridge donnaient une periode reelle de cent trente-trois millisecondes, soit
    7,5 Hz au lieu des 10 attendus.
    La cadence dependait ainsi du temps de traitement, ce qui reintroduisait a
    petite echelle la fragilite que la separation des boucles venait de corriger :
    un Bridge plus lent aurait suffi a la faire deriver, et le reglage du
    correcteur avec elle.
    L'attente vise desormais la prochaine echeance. La cadence est tenue tant que
    le cycle rentre dans la periode, et degrade proprement au-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
2026-08-08 Audit du code, commentaires et retrait du code mort
    Documenter RATIO_REDUCTEUR comme non calibre : la valeur 50 est celle
    d'origine, jamais mesuree. Ajouter la formule de reglage et la raison du
    rejet du 90 annonce par le fabricant.
    Reecrire trois blocs de config.h qui decrivaient encore des valeurs
    remplacees depuis, et justifier le seuil d'obstacle a 25 cm : a 20 la
    decision se prenait sur la zone morte du LiDAR, d'ou la double detection.
    Uniformiser les commentaires sur la convention du projet. Retirer les quatre accesseurs et le handler on_lignes devenus
    inutilises cote MCU, ainsi que leurs pendants Python.
    Normaliser le formatage : espaces de fin de ligne, saut de ligne final.
    [bus_i2c.cpp, config.h]
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2026-08-09 Corriger et completer les references
    [config.h]
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2026-08-09 Reseau en trois constantes plutot qu'en detection a l'execution
    Le point d'acces est cree par le guide de deploiement avec une commande
    nmcli fixe. Le SSID et le mot de passe y sont choisis, et l'adresse en
    decoule : en mode partage, NetworkManager attribue 10.42.0.1 a l'interface
    et distribue le reste du sous-reseau aux clients. Les trois valeurs sont
    donc connues a la compilation.
    Retirer la machinerie qui decouvrait l'adresse a l'execution : le module
    reseau.py et ses trois methodes de detection, la RPC definir_reseau et son
    gestionnaire, la tache de republication periodique, et l'etat d'affichage
    differe du cote de l'ecran. Deux cent soixante-sept lignes, un chemin
    d'execution traversan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
    [config.h, sketch.ino]
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2026-08-10 Coque principale du châssis (SolidWorks)
    [body_vlad.SLDPRT]
2026-08-10 Support des capteurs
    [SG90 - Micro Servo 9g - Tower Pro.3.SLDPRT, ServoCage.SLDPRT]
2026-08-10 Fichiers STL pour impression 3D
    [TankuChanCockpitWithoutServoCage_V3.STL, blinker_w_gap.STL, headlight_w_gap.STL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]
2026-08-10 Fichier du matériel utilisé
    [BOM.xlsx]
